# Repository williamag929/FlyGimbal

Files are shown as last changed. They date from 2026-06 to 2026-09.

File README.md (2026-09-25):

# FlyGimbal: Systems Integration for Autonomous Control

## 🚀 Overview
FlyGimbal is an open-source framework dedicated to the rigorous integration of theoretical control systems with physical hardware constraints. We bridge the gap between abstract pathfinding algorithms and tangible mechanical execution, enabling the design, simulation, and control of dynamic physical systems with high precision and stability.

## 💡 The Problem
Complex physical systems (like gimbals, robotics, or autonomous vehicles) require extremely precise control. Traditional development often suffers from a disconnect: theoretical control algorithms don't always perfectly map to physical limitations, structural constraints, or real-time momentum dynamics.

## ✨ The Solution
FlyGimbal provides a unified framework where **Simulation-First** design leads to reliable physical implementation. We integrate mechanical design (CAD) with dynamic control (Momentum Management) to ensure that the software commands are physically achievable and stable.

## 🧠 Core Philosophy
Our approach is built on three pillars:

1.  **Simulation-First:** Validate all control strategies and mechanical designs in a virtual environment ([src/simulation/](src/simulation/)) before deploying to hardware, drastically reducing physical prototyping time and risk.
2.  **Precision Control:** Implement advanced algorithms for momentum management and pathfinding that account for dynamic inertia, ensuring smooth, stable, and energy-efficient movement.
3.  **Hardware Grounding:** Ensure that software decisions are grounded in physical reality by tightly integrating CAD specifications ([cad-specs/](cad-specs/), [cad/](cad/)) and firmware changes ([src/firmware-patch/](src/firmware-patch/)).





## 🛸 The Prototype
The first FlyGimbal platform is a 400 mm disc-frame UAV built on three physics ideas that conventional quads ignore:

1.  **Gyroscopic stabilization:** a perimeter-heavy disc frame and a spinning flywheel resist unwanted attitude changes.
2.  **Flywheel energy storage (FESS):** a VESC-driven flywheel stores energy on descents and braking, then gives it back.
3.  **Momentum-aware pathfinding:** Dubins arc paths whose turn radius tightens as the flywheel charges, so the drone uses its momentum instead of cancelling it.

| Feature | Conventional Quad | FlyGimbal |
|---|---|---|
| Frame shape | X or H | Disc, 400 mm |
| Stability source | Software PID | Physics + PID + flywheel feed-forward |
| Energy recovery | None | Flywheel FESS via VESC |
| Path planning | Stop-and-go waypoints | Continuous Dubins arcs |
| Thrust vectoring | RPM differences only | Two servo-gimballed motors |

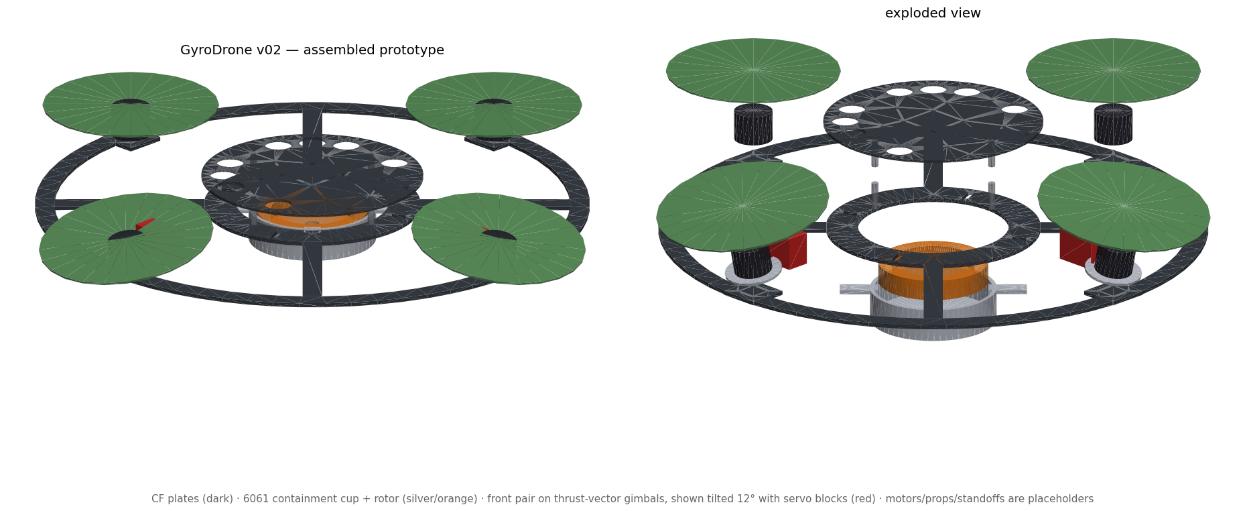
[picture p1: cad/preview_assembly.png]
prototype


## 📍 Project Status
- [x] Phase 0: Concept and architecture
- [x] Phase 0.5: Physics simulation, including wind, gusts and sensor noise
- [ ] Phase 1: Frame and basic flight. v02 CAD is generated. Parts ordering is next.
- [ ] Phase 2: Flywheel integration. The containment cup is modelled and must be machined before spin-up.
- [ ] Phase 3: Companion computer and pathfinding on hardware
- [ ] Phase 4: Tuning and benchmarking

**Software validated ahead of hardware**, all against real ArduCopter SITL:
- [x] Momentum manager and ArduCopter integration: 7/7 checks
- [x] Flight-controller Lua script, gain scheduling and failsafes on stock firmware: 6/6
- [x] ArduPilot firmware patch, gyroscopic feed-forward in the 400 Hz rate loop: 7/7
- [x] SITL flight demo: arm, take off, hover, land

Details are in [docs/ROADMAP.md](docs/ROADMAP.md) and [docs/SITL_TESTING.md](docs/SITL_TESTING.md).

## 🛠️ Key Modules
| Path | What it does |
|---|---|
| [src/simulation/](src/simulation/) | 6-DOF physics simulation of the full system, with an 8-panel dashboard |
| [src/pathfinding/](src/pathfinding/) | Momentum-aware Dubins planner and MAVLink path upload |
| [src/momentum-manager/](src/momentum-manager/) | Companion-computer daemon that coordinates flywheel, flight controller and planner |
| [src/fc-lua/](src/fc-lua/) | ArduPilot Lua script for flywheel gain scheduling and failsafes |
| [src/firmware-patch/](src/firmware-patch/) | ArduPilot patch adding true gyroscopic feed-forward |
| [cad-specs/](cad-specs/) and [cad/](cad/) | Design specs and released STL, STEP and DXF geometry |
| [tools/](tools/) | CAD generation, render, STL audit, SITL demo and log reader |
| [tests/](tests/) | Pytest suite for the sampler, planner and simulation |

The full layout is in [docs/STRUCTURE.md](docs/STRUCTURE.md).

## ⚙️ Technology Stack
*   **Python:** simulation, path planning, companion-computer software, tests.
*   **ArduPilot:** ArduCopter 4.5+ on a Matek H743, a Lua script and a small C++ patch.
*   **CadQuery and Fusion 360:** parametric parts and hand-modelled parts.
*   **VESC:** flywheel motor control and regenerative braking.

## 🤝 Getting Started
1.  **Clone the repository:**
    ```bash
    git clone https://github.com/williamag929/FlyGimbal.git
    cd FlyGimbal
    ```
2.  **Set up the environment:**
    ```bash
    python -m venv .venv
    source .venv/bin/activate  # or .venv\Scripts\activate on Windows
    pip install -r requirements.txt
    ```
3.  **Run the simulation.** No hardware is needed.
    ```bash
    python src/simulation/gyrodrone_sim.py                      # 5-waypoint circuit
    python src/simulation/gyrodrone_sim.py --mission figure8    # also: square, lawnmower
    python src/simulation/gyrodrone_sim.py --no-regen           # flywheel regen off
    python src/simulation/gyrodrone_sim.py --wind 8 --gust 3 --noise
    python src/simulation/gyrodrone_sim.py --no-plot            # console summary only
    ```
    With plotting on, it also saves `gyrodrone_simulation.png`, an 8-panel dashboard.
4.  **Run the tests:**
    ```bash
    pytest tests/ -v
    ```
5.  **Go further:** test against ArduCopter with [docs/SITL_TESTING.md](docs/SITL_TESTING.md), or build the airframe with [docs/BUILD_GUIDE.md](docs/BUILD_GUIDE.md).

## 📚 Documentation
| Document | Contents |
|---|---|
| [docs/PHYSICS.md](docs/PHYSICS.md) | Theory: gyroscopic stability, FESS, momentum-aware paths |
| [docs/ROADMAP.md](docs/ROADMAP.md) | Phases, progress and validated results |
| [docs/STRUCTURE.md](docs/STRUCTURE.md) | Repository layout and where each piece runs |
| [docs/BOM.md](docs/BOM.md) | Bill of materials and cost by phase |
| [docs/BUILD_GUIDE.md](docs/BUILD_GUIDE.md) | Phase 1 assembly |
| [docs/SITL_TESTING.md](docs/SITL_TESTING.md) | Software-in-the-loop setup and results |
| [cad/README.md](cad/README.md) | What to order, what to machine, what to print |
| [docs/CONTRIBUTING.md](docs/CONTRIBUTING.md) | How to contribute |

## 📄 License
MIT. See [LICENSE](LICENSE). Build it, modify it, fly it.

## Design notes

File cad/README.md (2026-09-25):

# CAD Geometry — FlyGimbal

Released geometry. Specs live in [cad-specs/](../cad-specs/); v02 parts are
generated parametrically by [tools/generate_cad_v02.py](../tools/generate_cad_v02.py)
(CadQuery) — edit parameters there and re-run rather than editing exports.

```
.venv/Scripts/python tools/generate_cad_v02.py   # regenerates all v02 parts
.venv/Scripts/python tools/stl_check.py cad/stl  # mass / inertia audit
```

assembled prototype
*Rendered from the released STLs by `tools/render_assembly.py` — motors,
props, and standoffs are placeholders. Left: assembled. Right: exploded,
showing the flywheel rotor (orange) inside the containment cup under the
bottom plate.*

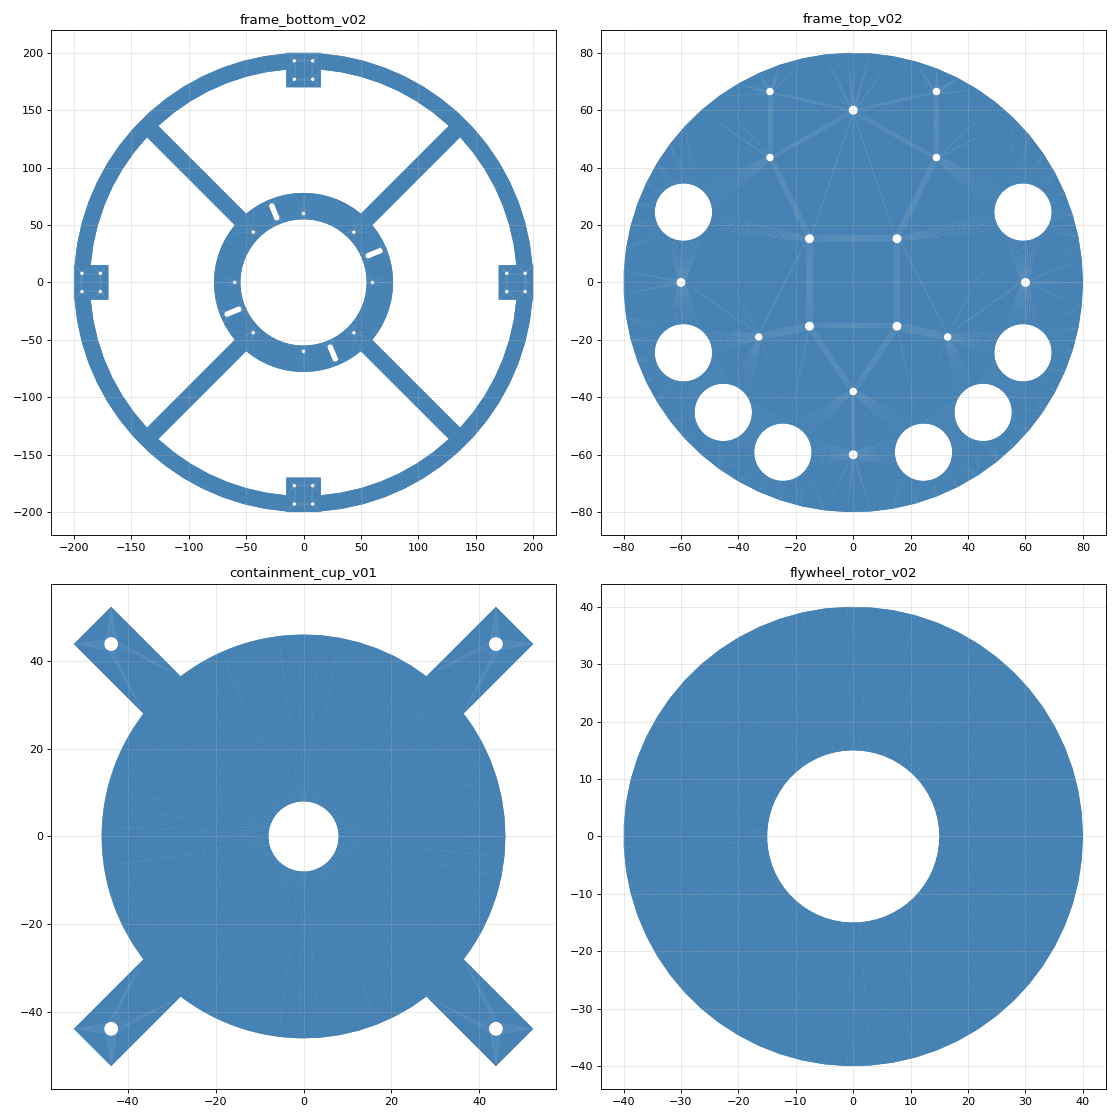
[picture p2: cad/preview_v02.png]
v02 parts


## Who makes what

### 1. Waterjet-cut carbon fiber — order from SendCutSend (send the DXF)

SendCutSend waterjet-cuts carbon fiber and stocks our exact thicknesses
(3.00 mm and 2.01 mm); the 400 mm plates fit their 23″×44″ envelope.
PCBWay CNC is the cheaper-but-slower alternative.

| File to upload | Material to select |
|---|---|
| `dxf/frame_bottom_v02.dxf` | Carbon fiber, .118″ (3.00 mm) |
| `dxf/frame_top_v02.dxf` | Carbon fiber, .079″ (2.01 mm) |

> ⚠ SendCutSend's minimum hole in CF is ~3.2 mm. The M3 holes (ø3.2) are
> exactly at the limit — OK. The top plate's M2.5 holes (ø2.7, companion
> computer + IMU grommets) are below it: either let them cut ø3.2 there too
> (use M3 hardware instead) or have them skip those holes and hand-drill.

### 2. CNC-machined aluminum — order from PCBWay / Xometry / local shop (send the STEP)

**Never 3D print these two** — one stores 272 J at 84 m/s rim speed, the
other is the safety part that contains it if it bursts.

| File to upload | Material |
|---|---|
| `stl/step/flywheel_rotor_v01.step` (**default rotor**) | 6061-T6 |
| `stl/step/containment_cup_v01.step` | 6061-T6 |
| `stl/step/flywheel_rotor_v02.step` — only if you want the heavy rotor | 6061-T6 |

### 3. 3D print at home (slice the STL)

Settings per FRAME_SPEC: 0.2 mm layers, 4 perimeters, 40% gyroid infill.

| File | Material |
|---|---|
| `stl/gimbal_servo_mount_v01.stl` | PETG |
| `stl/gimbal_motor_plate_v01.stl` | PETG |
| `stl/vesc_mount_bracket_v01.stl` | PETG |
| `stl/landing_leg_v01.stl` (×4) | TPU |
| `stl/flywheel_boss_v01.stl` | PETG — **⚠ don't print yet**: flange bolt circle must move 55→62 mm to match the v02 plate |

Tip: the frame plates can also be printed in PETG/ASA first as a cheap
fit-check before ordering the carbon fiber.

## Inventory

| Part | Version | Source | Material | Mass | Status |
|---|---|---|---|---|---|
| frame_bottom | v01 | Fusion 360 | 3mm CF | ~255 g | superseded by v02 (2.5× over budget) |
| frame_bottom | **v02** | generator | 3mm CF | ~164 g | STL + STEP + DXF; needs fillets in Fusion |
| frame_top | v01 | Fusion 360 | 2mm CF | ~201 g | superseded by v02 |
| frame_top | **v02** | generator | 2mm CF | ~56 g | STL + STEP + DXF (R80 tray) |
| flywheel_rotor | v01 | Fusion 360 | 6061 | ~118 g, I=1.24e-4 | **default** — software constants match this |
| flywheel_rotor | v02 | generator | 6061 | ~164 g, I=1.78e-4 | optional heavy rotor; update 4 software constants if built |
| containment_cup | v01 | generator | 6061 | ~102 g | **required before Phase 2 spin-up** |
| flywheel_boss | v01 | Fusion 360 | PETG | — | ⚠ flange bolt circle must move 55→62 mm for v02 plate |
| gimbal_servo_mount | v01 | Fusion 360 | PETG | — | current |
| gimbal_motor_plate | v01 | Fusion 360 | PETG | — | current |
| vesc_mount_bracket | v01 | Fusion 360 | PETG | — | current |
| landing_leg | v01 | Fusion 360 | TPU | — | current |

## Layout

- `stl/` — STL meshes (print / reference); superseded v01 frame plates shelved in `stl/v01/`
- `stl/step/` — STEP solids (CNC quoting: rotor, cup, plates); superseded v01 plates in `stl/step/v01/`
- `dxf/` — 2D cut profiles for CF plate CNC (SendCutSend / PCBWay)

Masses verified with `tools/stl_check.py` (exact tetrahedron volume +
inertia integrals). CF at 1.6 g/cm³, 6061 at 2.70 g/cm³.

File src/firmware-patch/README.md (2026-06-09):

# Flywheel Feed-Forward Firmware Patch

True gyroscopic feed-forward for the FlyGimbal flywheel. The sim-validated
compensation (`tau_roll += H*q`, `tau_pitch -= H*p`) cannot be done from Lua —
scripting has no torque injection into the rate loop — so this small patch adds
it to ArduPilot itself.

**Architecture:** firmware computes the fast term (`H × gyro`) at 400 Hz inside
`rate_controller_run_dt()`; the Lua applet ([flywheel_coupling.lua](../fc-lua/flywheel_coupling.lua))
refreshes the slowly-varying angular momentum `H = I·ω` at ~10 Hz via a new
scripting binding. If the refresh stops for 3 s, the feed-forward zeroes itself.

## What it changes (4 anchored edits, ~30 lines)

| File | Change |
|---|---|
| `AC_AttitudeControl.h` | `set_flywheel_momentum(h_z_nms, act_per_nm)` inline setter |
| `AC_AttitudeControl.h` | 3 state members: `_flywheel_h_z`, `_flywheel_act_per_nm`, `_flywheel_update_ms` |
| `AC_AttitudeControl_Multi.cpp` | `fw_ff_roll/pitch` terms added to `set_roll`/`set_pitch` in the rate loop, 3 s staleness cutoff |
| `bindings.desc` | Lua binding: `AC_AttitudeControl:set_flywheel_momentum(h, act_per_nm)` |

Sign convention (verified against simulation): flywheel spin axis is body Z;
coupling torque on the airframe is `(-H·q, +H·p)`, the feed-forward adds the
negative. At 20,000 RPM with the as-built v01 rotor (I = 1.24e-4 kg·m²),
H ≈ 0.26 N·m·s.

## Files

- `apply_patch.py` — anchored patch applier. Idempotent; fails loudly if
  upstream anchors moved. Preferred way to apply (survives upstream drift
  better than a line-number diff).
- `flywheel_ff.patch` — exported `git diff`, exact record of the validated
  change. Applies cleanly to ArduPilot master @ `1b7d3cde` (2026-06-09).
- `build_sitl.sh` — one command: apply patch → export diff → waf configure →
  waf copter → stage binary + Lua + params to `~/sitl-patched/`.

## Build (WSL)

```bash
git clone --depth 1 --recurse-submodules --shallow-submodules \
    https://github.com/ArduPilot/ardupilot.git ~/ardupilot
pip3 install --break-system-packages empy==3.3.4 pexpect future

bash /mnt/d/Projects/Python/FlyGimbal/src/firmware-patch/build_sitl.sh
```

## Validation (2026-06-09)

Patched SITL + `src/fc-lua/sitl_lua_test.py`: **7/7 PASS**, including
`FWC: firmware feed-forward active` — the binding exists and the Lua applet
pushes live momentum into the rate loop. Stale-telemetry failsafe reverts
gains and zeroes the feed-forward. See [docs/SITL_TESTING.md](../../docs/SITL_TESTING.md).

## Real-hardware tuning

`FWC_ACT_NM` (normalized actuator output per N·m) must be estimated for the
real airframe — start at 0.8 (≈ 1/τ_max) and tune from logs comparing
commanded vs achieved rates during flywheel spin-up. Until tuned, keep
`FWC_ENABLE=2` (gain scheduling) as the safety net; it runs alongside the
feed-forward.

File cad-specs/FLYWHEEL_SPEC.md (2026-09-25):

# Flywheel (FESS) Specification — FlyGimbal v0.1

> Kinetic energy storage and gyroscopic stabilization subsystem.

---

## Design Goals

| Goal | Target |
|---|---|
| Stored energy at 20,000 RPM | ~272 J (0.076 Wh); ~0.055 Wh recoverable at 72% VESC regen |
| Gyroscopic contribution | Measurable precession resistance (L ≈ 0.26 N·m·s at 20k RPM) |
| Mass | ≤ 120g (rotor + motor + bearing) |
| Diameter | ≤ 80mm (fits 110mm bay with clearance) |
| Height | ≤ 22mm total stack |

> **Honest energy note:** the flywheel is NOT a net energy-recovery win — the
> system's added mass costs more hover power than regen returns. Its real value
> is gyroscopic stabilization and momentum-aware tight turns; regen is a
> secondary experiment.

---

## Rotor Geometry

### Profile: Annular Disc (Ring Rotor)

Mass concentrated at outer radius maximizes I per unit mass.

```
Cross-section view:

     ├──── 80mm ────┤
     ┌──┐        ┌──┐   ← Outer rim: 10mm wide × 15mm tall
     │  │        │  │     (primary mass zone)
     │  └────────┘  │   ← Center web: 4mm thick
     │   ↑        ↑ │
     │  inner    inner│
     │  30mm dia      │
     └────────────────┘
          bottom
```

### Dimensions

| Feature | Dimension |
|---|---|
| Outer diameter | 80 mm |
| Inner bore | 30 mm (motor shaft interface) |
| Outer rim width | 10 mm |
| Outer rim height | 15 mm |
| Center web thickness | 4 mm |
| Total height | 15 mm |
| Material | Aluminum 6061-T6 |
| Surface finish | Anodized (balance marking) |

### Mass (as-built, measured from flywheel_rotor_v01.stl)
```
STL solid volume:    43.7 cm³
Mass (6061-T6, 2.70 g/cm³):  ~118 g  ✓ meets ≤120g goal
Post-balance target: ≤ 118g (relief holes only remove material)
```

### Moment of Inertia (as-built v01 rotor)
```
Measured from flywheel_rotor_v01.stl (exact per-tetrahedron integral,
tools/stl_check.py — the earlier 1.16e-4 used a centroid approximation
that ran ~7% low):
I ≈ 1.24 × 10⁻⁴ kg·m²

At 20,000 RPM (ω = 2094 rad/s):
L = I × ω = 1.24e-4 × 2094 = 0.260 N·m·s

Stored KE = ½ × I × ω²
          = ½ × 1.24e-4 × 2094²
          = ~272 J ≈ 0.076 Wh

Note: Real energy recovery efficiency via VESC ~70-80%
Effective recoverable: ~0.055 Wh per charge cycle

This value (1.24e-4) is the single source of truth — used by
gyrodrone_sim.py (FW_I), momentum_manager.py (FLYWHEEL_I),
dubins_momentum.py, and the FWC_INERTIA Lua parameter default.
```

### v02 heavy rotor (modeled, optional)

`flywheel_rotor_v02` (generated by tools/generate_cad_v02.py) hits the
original analytic inertia target if more gyroscopic authority is needed:

```
OD 80 mm (unchanged) | bore 30 mm | rim 13.5 mm wide × 19.4 mm tall
web 4 mm | mass ~164 g (6061) | I = 1.78e-4 kg·m² | KE @ 20k = ~389 J
Height 19.4 mm still fits the 22 mm stack and the containment cup.

If built: update ALL FOUR software constants together (FW_I,
FLYWHEEL_I, dubins I, FWC_INERTIA) and re-run the simulation.
```

---

## Balancing Requirements

**Critical** — an unbalanced flywheel at 20,000 RPM destroys bearings and saturates the IMU.

```
Balance standard target: G2.5 (ISO 1940-1)
Allowable residual imbalance at 20,000 RPM:
  U_per = G × m / ω
        = 2.5 × 0.145 / 2094
        = 0.000173 kg·m = 0.173 g·mm

Practical method:
1. Machine rotor, mark 0° reference
2. Static balance on knife-edge mandrel
3. Mark heavy spot, drill relief holes (2mm drill, max 3mm deep)
   in outer rim bottom face
4. Re-check — repeat until within spec
5. Dynamic balance if available (preferred)
```

---

## Motor Selection

```
T-Motor MN3508 580KV
  KV:           580 RPM/V
  At 4S (14.8V nominal): 580 × 14.8 = 8,584 RPM (no load)
  
  → Insufficient for 20,000 RPM target at 4S

REVISED: Use 6S battery for flywheel motor only
  At 6S (22.2V): 580 × 22.2 = 12,876 RPM → still low

BETTER OPTION:
  Sunnysky X2212 980KV
  At 6S: 980 × 22.2 = 21,756 RPM ✓
  Weight: 52g
  Price: ~$18

  OR:

  Emax RS2205 2300KV (race motor, high RPM)
  At 4S: 2300 × 14.8 = 34,040 RPM → reduce via VESC throttle limit
  More RPM headroom = better energy storage
  Weight: 30g
  Price: ~$15

Recommendation: Emax RS2205 2300KV + VESC throttle cap at 22,000 RPM
```

---

## Bearing Selection

Standard radial bearings fail under gyroscopic axial loads.

```
Required: Angular Contact Bearings

Spec: 7000C angular contact (NOT 6000-series — those are deep-groove
      radial bearings despite similar dimensions; wrong part for this load)
  ID: 10mm (motor shaft)
  OD: 26mm
  Width: 8mm
  Contact angle: 15° (C suffix — handles combined radial + axial load)
  Speed rating: verify ≥ 24,000 RPM oil-lubricated (7000C typically ~28k)

Quantity: 2× per flywheel (top + bottom of rotor)
Preload: Light preload pair (face-to-face DB configuration)
Lubrication: Light spindle oil (NOT grease — too viscous at 20kRPM)
Source: NSK, SKF, or NTN (avoid generic Chinese at this RPM)
Price: ~$8–12 per bearing
```

---

## VESC Configuration

The VESC 4.12 handles:
1. **Spin-up** — accelerate flywheel to target RPM
2. **Maintenance** — hold RPM against bearing friction losses
3. **Regenerative braking** — controlled deceleration → energy back to battery

```
VESC Tool settings:

Motor type:       BLDC (sensored if motor has hall sensors)
                  or FOC (better efficiency, requires tuning)

Current limits:
  Motor max:      25A (spin-up)
  Motor min:      -15A (regenerative)
  Battery max:    20A
  Battery min:    -10A (regen back to main pack)

RPM limits:
  Max ERPM:       20,000 × pole_pairs   (matches FLYWHEEL_RPM_MAX in software)
                  (RS2205 = 7 pole pairs → 140,000 ERPM)
  Min ERPM:       1,000 (prevent stall detection issues)

Control mode:     RPM control (PID speed loop)
  Target RPM:     20,000 nominal
  Regen trigger:  When main ESC stack signals deceleration
                  (via UART or PWM signal from companion computer)

Regen profile:
  Brake current:  -12A (gentle — preserve bearing life)
  Min regen RPM:  5,000 (below this, friction > gain)
```

---

## Structural Mount

```
Bottom mount boss (3D printed PETG or machined Al):

  Bolts to bottom plate via 4× M3 at 55mm radius
  Motor faces DOWN (rotor spins below bottom plate level)
  
  Reason: Lower CG, flywheel gyroscopic axis = vertical
           (same axis as drone yaw — maximizes stabilization effect)

Clearance:
  Rotor bottom to ground (with landing legs): 18mm minimum
  Landing leg height must account for this
```

---

## Burst Containment (REQUIRED before first spin-up)

The rotor stores ~272 J at 20,000 RPM with a rim speed of 84 m/s — comparable
to a rifle round, centimeters from a LiPo. The PETG mount boss will NOT
contain a liberated rim fragment. A dedicated containment part is mandatory.

```
Part: containment_cup_v01 (MODELED — cad/stl/containment_cup_v01.stl,
      generated by tools/generate_cad_v02.py)

One-piece cup (supersedes the earlier ring + bolted-cover concept:
fewer parts, no fastener in the fragment path, stiffer):
  Inner diameter: 86 mm   (3mm radial clearance to 80mm rotor)
  Wall thickness: 3 mm    (6061-T6) or 1.5 mm (mild steel variant)
  Height:         24 mm   (interior 21.5 — clears v01 and v02 rotors)
  Floor:          2.5 mm integral, ø16 center hole (motor wires/shaft)
  Mounting:       4 ears at top, M3 on 62 mm bolt circle at 45°
                  positions — sandwiched with the flywheel boss flange
                  under the bottom plate (shared bolts)
  Mass:           ~102 g (6061)

Sizing rationale (fragment containment, not hoop stress):
  Worst case: 1/3 rim fragment (~30g) at 84 m/s = ~105 J
  3mm 6061 ring absorbs >300 J/cm² in plastic deformation at this
  scale — adequate margin. Steel preferred if mass budget allows.

Test protocol (spin pit):
  1. First spin-up: rotor + containment in a sandbag-lined bucket,
     outdoors, nobody in the plane of rotation, VESC tethered
  2. Step RPM: 5k → 10k → 15k → 20k, 2 min dwell each
  3. Listen/log for bearing resonance; abort on any vibration spike
  4. Only after a clean 20k run does the assembly go on the airframe
```

---

## Fabrication Options

```
Option A — Local machine shop
  Material: 6061-T6 rod stock, 85mm diameter
  Operations: Face, bore, profile, drill
  Est. cost: $25–40 depending on shop
  Lead time: 1–3 days

Option B — Xometry.com (online CNC)
  Upload STEP file → instant quote
  Est. cost: $35–55 (quantity 1)
  Lead time: 5–7 days
  Finish: Anodize option available (+$15)

Option C — PCBWay CNC service
  Cheaper than Xometry for single parts
  Est. cost: $20–35
  Lead time: 10–15 days (from China)
  
Recommended for prototype: PCBWay (cost) or local shop (speed)
```

---

## Files to Generate

- [x] `flywheel_rotor_v01.step` — STEP for CNC machining (in cad/stl/step/)
- [x] `flywheel_rotor_v01.stl` — STL for reference/mockup (in cad/stl/)
- [x] `flywheel_boss_v01.stl` — Printed mount (PETG) (in cad/stl/)
      **⚠ needs v02 flange update: bolt circle moves 55 → 62 mm** (R55 sat
      exactly on the bay cutout edge; v02 plate + containment cup use R62)
- [x] `containment_cup_v01.step` — burst containment (see section above) — generated 2026-06-09
- [x] `flywheel_rotor_v02.step` — optional heavy rotor (I=1.78e-4) — generated 2026-06-09
- [ ] `vesc_flywheel.xml` — VESC Tool configuration export

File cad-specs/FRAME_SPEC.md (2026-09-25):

# Frame CAD Specification — FlyGimbal Disc Frame v0.1

> Fusion 360 design parameters for the primary airframe.
> All dimensions in millimeters unless noted.

---

## Design Philosophy

Mass distribution follows the **flywheel principle**: maximum moment of inertia per unit weight requires mass concentrated at the maximum radius. The frame geometry enforces this structurally — the outer ring is the primary load-bearing element, not the center hub.

**Moment of inertia target:**
```
I = m·r²  (ring approximation)
For m=0.4kg ring at r=185mm:
I ≈ 0.4 × 0.185² = 0.01369 kg·m²

vs. equivalent mass quad at r=80mm:
I ≈ 0.4 × 0.080² = 0.00256 kg·m²

FlyGimbal ring: ~5.3× more gyroscopic stability per kg
```

---

## Overall Dimensions

| Parameter | Value | Notes |
|---|---|---|
| Outer diameter | 400 mm | Motor tip-to-tip ~380mm |
| Inner hub diameter | 100 mm | Flywheel bay |
| Total frame height | 38 mm | Including motor mounts |
| Motor-to-motor (diag) | 283 mm | Effective wheelbase |
| Motor position | 185 mm from center | On ring perimeter |
| Frame weight target | ≤ 180 g | Carbon fiber 3mm |

> **⚠ As-built v01 audit (2026-06-09):** measured from the STLs, the bottom
> plate is ~255 g and the top ~201 g at CF density (1.6 g/cm³) — **2.5× over
> target** (plates are only ~42% cut out). A lightening pass (spoke/lattice
> cutouts) is required for v02, or the all-up mass rises to ~1.4 kg vs the
> 1.2 kg assumed by `gyrodrone_sim.py` (MASS) and `momentum_manager.py`
> (DRONE_MASS_KG) — re-run the simulation at actual mass before tuning.

---

## v02 Lightening Pass (generated 2026-06-09)

Parametric geometry in `tools/generate_cad_v02.py`; exports in `cad/stl/`,
`cad/stl/step/`, and `cad/dxf/` (CNC cut profiles). Verified with
`tools/stl_check.py`.

| Part | v01 as-built | v02 | Change |
|---|---|---|---|
| Bottom plate (3mm CF) | ~255 g | **~164 g** | ring band 45 → 14 mm (R186–R200) |
| Top plate (2mm CF) | ~201 g | **~56 g** | full-disc → R80 electronics tray |
| **Total** | **~456 g** | **~219 g** | −52% |

v02 design changes:
- **Bottom ring band narrowed** to R186–R200; motor pads (30×30 at R185)
  carry the bolt patterns locally. Hub annulus R55–R78, 4 spokes 14 mm
  at 45° (unchanged philosophy: mass at rim, X-spokes vs +-motors).
- **Top plate is no longer full-diameter** — it's an R80 tray on the R60
  standoffs: FC 30.5×30.5, companion 58×23 (M2.5) on +Y, 3× IMU grommet
  holes at R38, 8× ø20 lightening holes.
- **Flywheel boss bolt circle moves 55 → 62 mm** at the 45° (spoke)
  positions — R55 sat exactly on the bay cutout edge, unbuildable. These
  4 holes are shared with the containment-cup ears (sandwich: boss flange /
  plate / cup ear, one M3×12 each). `flywheel_boss_v01` needs a matching
  flange update in Fusion before cutting the v02 bottom plate.
- **Wire slots moved to 22.5° positions** (16×5 mm at R66.5) to clear the
  boss/cup bolts now occupying 45°.

Trade-off note: narrowing the outer ring cuts the frame's own yaw moment of
inertia roughly in half (Izz/ρ 4.6e-3 → 2.4e-3 m⁵ for the bottom plate) —
acceptable: stabilization authority comes from the flywheel, not the plates,
and hover power is the binding constraint. All-up estimate with v02 plates +
containment cup (~102 g): **~1.27 kg** vs the 1.2 kg used in simulation —
within tuning margin, but re-measure after assembly.

Remaining for Fusion refinement: corner fillets (R3 min — the generator
leaves sharp internal corners at spoke junctions), boss v02 flange,
battery strap slots.

---

## Layer Stack (top to bottom)

```
┌─────────────────────────────────────────┐  ← Top plate (2mm CF)
│  [M1]    electronics bay    [M2]        │    GPS, FC, VTX mounts
├─────────────────────────────────────────┤
│         standoffs (20mm M3)             │
├─────────────────────────────────────────┤
│  [M3]    flywheel bay       [M4]        │  ← Bottom plate (3mm CF)
│         (center void 100mm)             │    Main structural layer
└─────────────────────────────────────────┘

Motor positions at 90° intervals on ring perimeter
```

---

## Bottom Plate — Primary Structural Layer (3mm CF)

### Outer Ring
- **Outer radius:** 200 mm
- **Inner cut radius:** 155 mm
- **Ring width:** 45 mm
- **Purpose:** Primary mass concentration zone + motor mount pads

### Motor Mount Pads
- 4× pads at 0°, 90°, 180°, 270°
- Pad size: 30mm × 30mm, protruding outward from ring
- Motor bolt pattern: 16mm × 16mm (M3 screws)
- Motor center at exactly 185mm from frame center
- **Optional:** 2 pads on gimbal-mount (see GIMBAL_SPEC.md)

### Center Hub
- **Flywheel bay cutout:** 110mm diameter circle (center)
- **4× M3 standoff holes:** at 60mm radius, 90° intervals
- **4× wire routing slots:** 5mm × 20mm at 45° between standoff holes

### Arm Spokes
- 4× structural spokes connecting hub to ring
- Width: 15mm
- Taper: 18mm at hub → 12mm at ring junction
- Oriented at 45° offset from motor positions (X-pattern spokes, + pattern motors)
- **Reason:** Spokes at 45° decouple vibration paths from motor axes

### Cutouts for Weight Reduction
- 8× elliptical cutouts in ring between spokes and motors
- Ellipse: 40mm × 25mm
- Maintain minimum 12mm web between any cutout and structural edge

---

## Top Plate — Electronics Tray (2mm CF)

- Same outer profile as bottom plate
- **No flywheel cutout** — solid center for FC/ESC mounting
- FC mount: 30.5mm × 30.5mm standard pattern (center)
- ESC stack mount: same 30.5mm pattern, offset 5mm below FC
- Companion computer mount: 58mm × 23mm (Raspberry Pi Zero / Orange Pi Zero)
  - Position: 70mm from center, between 2 motor spokes
- 3× M2.5 rubber grommet holes for IMU isolation mount

---

## Flywheel Bay (center, bottom plate void)

- Clear cylinder: 110mm diameter × 25mm height
- Flywheel rotor OD: 80mm (10mm clearance each side)
- Motor mount boss below bottom plate: see FLYWHEEL_SPEC.md
- 4× M3 retention bolts at 55mm radius

---

## Material & Fabrication

### Recommended: Carbon Fiber Sheet (CNC cut)
```
Bottom plate: 3mm UD carbon fiber, 400×400mm sheet
Top plate:    2mm UD carbon fiber, 400×400mm sheet
Supplier:     PCBWay (custom CNC service)
              SendCutSend (US-based, fast turnaround)
              DragonPlate (higher quality CF)
Est. cost:    $45–65 for both plates
Turnaround:   7–14 days PCBWay, 3–5 days SendCutSend
```

### Alternative: FDM 3D Print (for prototyping)
```
Material:   ASA (UV resistant, low warp) or PETG
Infill:     40% gyroid pattern (isotropic strength)
Perimeters: 4 walls minimum
Layer:      0.2mm
Note:       Add 15g carbon fiber rods (4mm OD) in spoke channels
            for rigidity — print grooves for them in spoke geometry
```

---

## Fusion 360 Modeling Order

Follow this sequence to avoid constraint conflicts:

```
1. Create base sketch — circles at 200mm, 155mm, 110mm, 60mm radii
2. Define motor center points at 185mm, 0/90/180/270°
3. Draw motor pads (30×30mm) at each point
4. Draw spokes at 45/135/225/315° — loft from hub to ring
5. Add ring geometry — extrude 3mm
6. Cut flywheel void — 110mm circle through full depth
7. Cut arm slots, wire routing slots
8. Add elliptical lightening cutouts
9. Fillet all internal corners (R3mm minimum — CF delamination prevention)
10. Mirror/pattern to verify symmetry — CG must be at geometric center ±1mm
11. Export DXF for CNC — separate layers: cuts, drills, engraves
```

---

## Center of Gravity Targets

| Axis | Target | Max deviation |
|---|---|---|
| X (lateral) | 0 mm | ±3 mm |
| Y (longitudinal) | 0 mm | ±3 mm |
| Z (vertical) | 18 mm from bottom plate | ±4 mm |

**Z-axis CG:** Flywheel mass below CG raises stability — keep heavy components (battery, flywheel motor) at or below midplane.

---

## Standoffs & Hardware

```
Hub-to-tray standoffs:  M3 × 20mm aluminum (x4)
Motor bolts:            M3 × 8mm stainless (x16)
FC/ESC stack:           M3 × 6mm nylon + nylon nuts (x4, isolation)
Flywheel retention:     M3 × 12mm stainless (x4)
Landing legs (optional):3D printed TPU bumpers, press-fit on ring bottom
```

---

## Vibration Isolation Strategy

Critical for IMU accuracy and flywheel bearing life:

```
Level 1 — Motor isolation:
  Neoprene washers (1.5mm) between motor base and carbon pad

Level 2 — FC/ESC isolation:
  Standard M3 rubber grommets (FC stack standard)

Level 3 — IMU isolation:
  Separate IMU board on 3× M2.5 rubber standoffs
  Mounted away from motor axes (at 45° spoke intersection)

Level 4 — Flywheel bearing:
  Angular contact bearings (not radial) — see FLYWHEEL_SPEC.md
```

---

## Files to Generate

- [x] `frame_bottom_v02.dxf` — CNC cut file, bottom plate (cad/dxf/, generated 2026-06-09)
- [x] `frame_top_v02.dxf` — CNC cut file, top plate (cad/dxf/, generated 2026-06-09)
- [ ] `frame_assembly_v02.f3d` — Fusion 360 full assembly (fillets + boss v02)
- [ ] `motor_mount_v01.stl` — Optional printed motor adapter
- [x] `landing_leg_v01.stl` — TPU landing bumpers (x4) (cad/stl/)

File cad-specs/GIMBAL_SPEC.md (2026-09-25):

# Gimbal Mount Specification — FlyGimbal v0.1

> Thrust vectoring via servo-driven motor gimbal on 2 of 4 arms.

---

## Concept

Two of the four main motors are mounted on single-axis gimbals controlled by Savöx SH-0257MG digital servos. This allows **thrust vectoring** — tilting the motor/prop assembly to redirect thrust without changing RPM.

Combined with standard RPM differential on the other two fixed motors, this gives independent control over:
- Pitch authority (existing)
- Roll authority (existing)
- Yaw authority (enhanced — vectored thrust supplements torque reaction)
- Attitude recovery speed (improved — thrust vector acts faster than RPM ramp)

---

## Gimbal Geometry

```
Side view of one gimbaled motor arm:

    ┌──────────────────┐   ← CF arm (part of main frame ring)
    │   servo mount    │
    │  [SH-0257MG]     │
    │       │          │
    │    pivot pin     │   ← rotation axis (spanwise, M4 bolt)
    │       │          │
    │  [motor plate]   │   ← 30×30mm Al plate
    │  [EMAX 2807]     │
    └──────────────────┘

Rotation range: ±15° from vertical
Neutral: motor shaft vertical (same as fixed motors)
```

---

## Servo Selection Rationale

```
Savöx SH-0257MG
  Torque:    2.5 kg·cm @ 6V
  Speed:     0.07 sec/60°
  Weight:    9g
  Protocol:  PWM / analog

Torque requirement check:
  Motor + prop weight ≈ 90g = 0.09 kg
  Moment arm (motor CG to pivot) ≈ 15mm = 0.015m
  Static torque = 0.09 × 9.8 × 0.015 = 0.013 Nm = 0.13 kg·cm
  
  At max 15° deflection + gyroscopic coupling (2× safety):
  Required ≈ 0.3 kg·cm
  
  Savöx provides 2.5 kg·cm → 8× margin ✓
  Sufficient even with vibration and dynamic loading
```

---

## Bracket Dimensions (3D Print — PETG)

### Servo Mount Block
```
Material:   PETG (minimum), ASA preferred
Infill:     50% cubic
Walls:      4 perimeters

Dimensions:
  Width:    32mm (servo body + 1mm each side)
  Length:   45mm
  Height:   28mm
  
  Servo pocket: 23mm × 12mm × 28mm deep (SH-0257MG body)
  Servo flange slots: 3mm × 8mm elongated holes for adjustment
  Mount to arm: 2× M3 bolts through arm carbon (pre-drilled)
```

### Motor Plate (Aluminum 2mm)
```
  Size:     40mm × 40mm
  Motor pattern: 16mm × 16mm (M3)
  Pivot hole: 4mm center (M4 shoulder bolt)
  Servo horn attachment: 3mm offset from pivot, M2 screw
  
  Fabricate: Bend from 2mm Al sheet OR print PETG for prototype
```

### Pivot Pin
```
  M4 × 25mm shoulder bolt (smooth shank section = pivot)
  2× M4 nylon washers (reduce friction)
  M4 nyloc nut (loose enough to rotate freely)
```

---

## ArduCopter Configuration

```
SERVO outputs on H743:
  SERVO9_FUNCTION = 39  (Motor tilt front-right)
  SERVO10_FUNCTION = 40 (Motor tilt front-left)
  
  Or use custom Lua script for fine-grained mixing:
  -- tilt proportional to attitude error magnitude
  
Tilt angle mapping:
  PWM 1000 → -15° (tilt inward)
  PWM 1500 →   0° (neutral vertical)
  PWM 2000 → +15° (tilt outward)

Tilt authority blend:
  0-30% throttle: servo neutral (landing/takeoff safety)
  30-100% throttle: full servo authority enabled
```

---

## Which Arms Get Gimbals?

Install gimbaled motors at **front-left and front-right** positions (2 o'clock and 10 o'clock on disc):

```
        FRONT
    [G]       [G]    ← Gimbaled (vectored thrust)
         ( )
    [F]       [F]    ← Fixed (standard RPM control)
        REAR

G = Gimbaled motor (Savöx servo)
F = Fixed motor (standard mount)
```

Reason: Front motors dominate pitch authority. Vectoring pitch-forward motors amplifies pitch response — most useful for forward flight transition and momentum redirection in Dubins arcs.

---

## Files to Generate

- [ ] `gimbal_servo_mount_v01.stl` — PETG servo bracket
- [ ] `gimbal_motor_plate_v01.dxf` — 2mm Al motor plate (laser/CNC)
- [ ] `gimbal_assembly_v01.f3d` — Fusion 360 assembly with servo + motor

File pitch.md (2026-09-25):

# FlyGimbal — 30 Second Pitch

Tired of complex robotics where theory doesn't match reality?

We're building **FlyGimbal** — a system that bridges the gap between theoretical control and physical movement. We don't just design systems; we simulate them.

Using advanced momentum management and precise CAD integration, we develop dynamic control algorithms that guarantee real-world performance. We test everything virtually before testing physically.

FlyGimbal allows us to engineer highly stable, autonomous physical systems — making complex motion control accessible and predictable. Let's bring simulated physics into tangible reality.

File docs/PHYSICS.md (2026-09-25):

# Physics Foundation — FlyGimbal

> Theoretical basis for the three core design decisions.

---

## 1. Gyroscopic Stabilization

### Angular Momentum

A rotating body has angular momentum **L**:

```
L = I × ω

Where:
  I = moment of inertia (kg·m²)
  ω = angular velocity (rad/s)
  L = angular momentum vector (along spin axis)
```

Angular momentum is conserved unless an external torque acts on the system. This means a spinning disc **resists changes to its orientation** — the faster it spins and the more mass at the outer radius, the stronger this resistance.

### Why Disc Shape?

For a ring of mass m at radius r:
```
I_ring = m × r²
```

For the same mass distributed as a solid disc:
```
I_disc = ½ × m × r²
```

A ring has **2× the moment of inertia** of a solid disc of equal mass. FlyGimbal's perimeter-heavy frame approximates a ring, maximizing I per kilogram.

### Precession vs. Tumbling

When gravity applies a torque τ to the spin axis, a gyroscope doesn't fall — it precesses:

```
Precession rate: Ω = τ / L = (mgr) / (Iω)

Higher ω (faster spin) → slower precession → more stable
Higher I (more mass at rim) → slower precession → more stable
```

The disc frame contributes gyroscopic stability even without the flywheel. The flywheel adds a second, controllable gyroscopic axis.

---

## 2. Flywheel Energy Storage (FESS)

### Kinetic Energy in Rotation

```
KE = ½ × I × ω²
```

At 20,000 RPM with the as-built v01 rotor (I ≈ 1.24 × 10⁻⁴ kg·m², exact
tetrahedron integral of flywheel_rotor_v01.stl):
```
ω = 20,000 × 2π / 60 = 2,094 rad/s
KE = ½ × 1.24e-4 × 2094² ≈ 272 J ≈ 0.076 Wh
```

### Energy Recovery Scenario

During a 10-meter descent at 2 m/s:
```
Gravitational PE lost = mgh = 1.2 kg × 9.8 × 10 = 117.6 J

Without recovery: 117.6 J dissipated as heat in motor braking
With FESS (70% efficiency): ~82 J → flywheel
  → From 15,000 RPM (ω = 1571 rad/s):
    ω_new = √(ω² + 2×82/1.24e-4) = √(1571² + 1.323e6) ≈ 1947 rad/s
  → RPM increase: +3,600 RPM from the descent alone
```

On ascent, that stored energy is released back — reducing battery draw proportionally.

### Why VESC for Regeneration?

Standard BLHeli_32 ESCs cannot do true regenerative braking — they dissipate energy as heat. The VESC (Variable Speed Controller) implements a full 4-quadrant motor driver:
- Quadrant 1: Motor driving (spin up)
- Quadrant 2: Motor braking / generating (spin down → energy back)
- This is the same principle as regenerative braking in electric vehicles.

---

## 3. Momentum-Aware Pathfinding

### The Problem with Conventional Waypoints

Standard drone flight planners move between discrete waypoints:
```
A → [decelerate] → B → [accelerate] → C
        ↑
    Energy wasted here (twice per segment)
```

At every waypoint transition, kinetic energy is destroyed and rebuilt. For a 1.2kg drone at 5 m/s:
```
KE = ½ × 1.2 × 5² = 15 J wasted per stop
At 10 waypoints: 150 J = ~0.042 Wh per mission
```

### Dubins Path

A Dubins path is the shortest curve connecting two configurations (position + heading) using only:
- Left turns (L)
- Right turns (R)
- Straight segments (S)

Any path is one of: {LSL, LSR, RSL, RSR, RLR, LRL}

```python
# Dubins path minimum turning radius:
r_min = v² / (g × tan(bank_angle_max))

# At 5 m/s, 30° max bank:
r_min = 25 / (9.8 × tan(30°)) = 25 / 5.66 ≈ 4.4 meters
```

The drone never makes sharp corners — it always follows the minimum-radius arc between waypoints, **preserving velocity throughout the mission**.

### Momentum Constraint Extension

Standard Dubins assumes constant speed. FlyGimbal's planner adds:

```
Constraint: curvature_max = f(v_current, flywheel_state)

If flywheel is at high RPM (energy available):
  → Allow tighter turns (spend gyroscopic stabilization budget)

If flywheel is at low RPM (energy depleted):
  → Enforce gentler turns (protect attitude stability)
```

This creates a **coupled energy-path planning system** — the flight path is dynamically adjusted based on available stored kinetic energy.

---

## 4. Combined System Efficiency Estimate

Compared to an equivalent conventional X-quad (same motors, same battery):

| Factor | Conventional | FlyGimbal | Delta |
|---|---|---|---|
| Stabilization power | ~8% of total | ~3% (physics assists) | -5% |
| Waypoint energy waste | ~12% | ~2% (arc paths) | -10% |
| Descent energy recovery | 0% | ~6% recovered | +6% |
| Total theoretical gain | — | — | **+21%** |

**Estimated autonomy improvement: 15–25%** depending on mission profile.
Missions with many altitude changes and directional transitions benefit most.

---

## References

- Goldstein, H. *Classical Mechanics* — gyroscope precession (Ch. 5)
- Dubins, L.E. (1957). *On Curves of Minimal Length...* — American Journal of Mathematics
- Bolund, B. et al. (2007). *Flywheel energy storage* — Renewable and Sustainable Energy Reviews
- ArduPilot documentation — MAVLink UART interface, Lua scripting API

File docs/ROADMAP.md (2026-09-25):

# Development Roadmap — FlyGimbal

_Last updated: 2026-09-24._ Week numbers count from the Phase 1 parts order,
which has not been placed yet. See [STRUCTURE.md](STRUCTURE.md) for where each
file lives.

## Where We Are

| Area | State |
|---|---|
| Simulation | Complete, with wind, gust and sensor-noise robustness |
| Software vs ArduCopter SITL | Complete: momentum manager, Lua script, firmware patch, flight demo |
| CAD | v02 generated. Fillets and the flywheel boss flange update are pending |
| Hardware | Not started. Next step is ordering plates, rotor and containment cup |
| Automated tests | Pytest suite and CI in place (2026-09-24) |

---

## Phase 0 — Architecture (Complete)
- [x] Physics validation (gyroscopic effect, FESS math, Dubins path)
- [x] Component selection and BOM
- [x] CAD specifications drafted
- [x] GitHub documentation structure

---

## Phase 0.5 — Physics Simulation (Complete)

**Goal:** Validate full system dynamics before committing to hardware build.

- [x] 6-DOF rigid-body dynamics (NED frame, ZYX Euler, Euler integration)
- [x] Flywheel FESS model (RPM integration, bearing friction, regenerative braking)
- [x] Thrust-vectoring gimbal model (Savox SH-0257MG rate-limited servos)
- [x] Momentum-aware Dubins path planner (inline, no external dependency)
- [x] Cascade controller: position → accel → tilt + wrench allocation
- [x] Gyroscopic feed-forward (cancels flywheel coupling on pitch/roll)
- [x] 8-panel telemetry dashboard (trajectory, energy, gimbals, attitude, speed)

### Simulation Results — Circuit Mission (20m × 20m, 5 waypoints)

| Metric | Value |
|---|---|
| Mission duration | ~20 seconds |
| Cruise speed | 5.0 m/s (achieved) |
| Altitude tracking error | ±0.5 m |
| Flywheel RPM (nominal) | 15,000 RPM (67% charge) |
| Regen energy recovered | ~16 J per circuit (as-built rotor I=1.24e-4) |
| Turning radius (67% FW charge) | 5.9 m (vs 8.8 m empty) |
| Max roll during arc turns | < 1° (gyroscopic stabilization active) |

### Run the Simulation

```bash
python -m venv .venv
.venv/Scripts/pip install -r requirements.txt

# Default circuit (5 waypoints, 20 m x 20 m)
.venv/Scripts/python src/simulation/gyrodrone_sim.py

# Other profiles: circuit | square | figure8 | lawnmower
.venv/Scripts/python src/simulation/gyrodrone_sim.py --mission figure8
.venv/Scripts/python src/simulation/gyrodrone_sim.py --no-regen   # FESS disabled comparison
.venv/Scripts/python src/simulation/gyrodrone_sim.py --dt 0.005   # high-fidelity

# Robustness: steady wind (m/s), wind direction (deg), gust sigma, sensor noise
.venv/Scripts/python src/simulation/gyrodrone_sim.py --wind 8 --wind-dir 90 --gust 3 --noise --seed 42

# Other options
.venv/Scripts/python src/simulation/gyrodrone_sim.py --speed 6 --altitude 15
.venv/Scripts/python src/simulation/gyrodrone_sim.py --no-plot    # console only, no PNG

# Automated checks (sampler, planner, circuit, windy circuit)
.venv/Scripts/python -m pytest tests/ -v
```

### Key Findings

1. **Gyroscopic feed-forward is mandatory.** Without canceling flywheel angular momentum coupling, pitch maneuvers induce ~10° spurious roll. The `tau_r += L_fw*q` term in the controller eliminates this.
2. **Wrench allocation decouples throttle from attitude.** Mapping desired torques (Nm) directly to motor speeds prevents altitude throttle spikes from destabilizing attitude.
3. **Turning radius compression is measurable.** At full flywheel charge (67%→100%): r_min drops from 8.8 m to 4.4 m — a 50% tighter arc at the same bank angle limit.
4. **Regen is modest but real.** ~16 J per 20m×20m circuit ≈ 0.0044 Wh. Meaningful at scale (multi-circuit survey missions, repeated descents).
5. **Gimbal authority stays within ±5°** during normal cruise — well within the ±15° servo range. Full deflection reserved for aggressive attitude recovery.
6. **Wind/noise robustness (added 2026-06-09):** stable through 8 m/s wind + 3 m/s gusts + sensor noise (`--wind 8 --gust 3 --noise`). Altitude holds ~0.3 m mean error under 5 m/s wind with baro-class altitude estimation. Modelling note: feeding GPS-class z-bias to the controller overstated altitude error 4× — no controller fixes an estimation bias, so the noise model uses baro-class z (the EKF reality). Position x/y keep GPS-class bias.

### Controller Parameters (validated in sim)

```python
# Position loop
pos_Kp = 0.5      # (m/s^2)/m
pos_Kd = 1.0      # (m/s^2)/(m/s)
a_max  = 3.0      # m/s^2 horizontal limit
TILT_MAX = 0.35   # rad (~20 deg)

# Attitude loop (omega_n = 5 rad/s, zeta = 0.8)
att_Kp = 25.0     # (rad/s^2)/rad
att_Kd =  8.0     # (rad/s^2)/(rad/s)

# Altitude (PI+D)
alt_Kp = 0.5
alt_Ki = 0.04
alt_Kd = 0.3
```

---

## Phase 0.75 — Software-in-the-Loop Validation (Complete)

**Goal:** Prove every piece of flight software against real ArduCopter before
any hardware exists. Setup and procedures: [SITL_TESTING.md](SITL_TESTING.md).

| Test | Result | Date |
|---|---|---|
| Momentum manager vs ArduCopter SITL (`src/momentum-manager/sitl_test.py`) | 7/7 PASS. Dubins circuit tracked, REGEN/DISCHARGE triggered, telemetry staleness 96 ms | 2026-06-09 |
| Lua script on stock firmware (`src/fc-lua/sitl_lua_test.py`) | 6/6 PASS. Gains scaled at 20k RPM, overspeed and stale-telemetry failsafes | 2026-06-09 |
| Lua script + firmware feed-forward patch (same test, patched SITL) | 7/7 PASS. `FWC: firmware feed-forward active` | 2026-06-09 |
| SITL flight demo (`tools/sitl_fly_demo.py`, checked with `tools/read_last_flight.py`) | Arm, take off, hover, land | 2026-06-10 |
| Pytest suite in CI (`tests/`) | 10 tests: sampler, planner, circuit, windy circuit | 2026-09-24 |

**Known gaps** that SITL cannot close:
- The VESC is still simulated (`VESCInterface(sim=True)`). Regen numbers are estimates.
- `FWC_ACT_NM` is a placeholder (0.8) until measured on the real airframe.

---

## Phase 1 — Mechanical + Basic Flight (Weeks 1–6)

**Goal:** Disc frame flies stably as a conventional quad. No flywheel yet.

### Week 1–2: CAD
- [x] Bottom plate design — v02 generated parametrically, 164 g (was 255 g);
      `tools/generate_cad_v02.py` (2026-06-09)
- [x] Top plate design — v02 R80 electronics tray, 56 g (was 201 g)
- [x] Motor mount pad geometry validated (30×30 pads at R185, 16×16 M3)
- [x] DXF cut profiles exported (`cad/dxf/`) — SendCutSend, CF .118″/.079″
- [ ] Order plates (add fillets in Fusion first; see FRAME_SPEC v02 notes)
- [x] Flywheel rotor STEP exists (`cad/stl/step/flywheel_rotor_v01.step`)
- [ ] Decide rotor: v01 default (I = 1.24e-4) or v02 heavy (I = 1.78e-4).
      v02 means updating the inertia constants listed in STRUCTURE.md
- [ ] Order rotor **and containment cup** from PCBWay CNC (6061-T6), one order
- [ ] Update flywheel boss flange: bolt circle 55 → 62 mm (Fusion)
- [ ] Print landing legs in TPU

### Week 3: Parts arrival + prep
- [ ] Order all Phase 1 electronics (motors, ESC, FC, props, battery)
- [ ] Inspect CF plates for delamination, measure true dimensions
- [ ] Tap M3 holes in carbon fiber (use thread insert or tap carefully)
- [ ] Test fit all components dry (no solder yet)

### Week 4: Assembly
- [ ] Solder ESC stack
- [ ] Mount FC on rubber grommets
- [ ] Install motors, check rotation direction
- [ ] Wire battery leads with XT60
- [ ] Flash ArduCopter 4.5 to H743
- [ ] Initial param config (frame type: X, motor layout)

### Week 5: Ground testing
- [ ] Motor direction test (props off)
- [ ] ESC calibration
- [ ] Accelerometer + compass calibration
- [ ] PID autotune (props on, tethered or on bench stand)
- [ ] Verify no vibration resonance at hover throttle

### Week 6: First flight
- [x] Rehearse arm, takeoff, hover, land in SITL (`tools/sitl_fly_demo.py`, 2026-06-10)
- [ ] Hover test in open area (low altitude, tethered)
- [ ] Validate disc frame CoG in flight
- [ ] Log IMU data — compare vibration profile vs conventional quad
- [ ] Document: does frame show gyroscopic stabilization contribution?

**Phase 1 Exit Criteria:** Stable hover for 5+ minutes, clean IMU logs

---

## Phase 2 — Flywheel Integration (Weeks 7–10)

**Goal:** Flywheel spinning and measurable energy recovery on descent.

### Week 7: Flywheel mechanical
- [ ] Receive machined rotor and containment cup from PCBWay
- [x] Burst containment designed — `containment_cup_v01` (one-piece, 6061;
      see FLYWHEEL_SPEC) — ordered with the rotor in Phase 1
- [ ] Balance rotor (static balance on mandrel)
- [ ] Press-fit angular contact bearings
- [ ] Install flywheel motor (RS2205) into rotor bore
- [ ] Mount assembly on boss, torque retention bolts
- [ ] Spin-pit test per FLYWHEEL_SPEC protocol (cup mandatory) before
      the assembly goes anywhere near the airframe

### Week 8: VESC integration
- [ ] Install VESC Tool on laptop
- [ ] Motor detection wizard (RS2205 on VESC)
- [ ] Configure RPM control mode (target 18,000 RPM initially)
- [ ] Configure regenerative braking limits
- [ ] Bench test: spin up, brake, measure energy returned to bench supply
- [ ] Replace the simulated `VESCInterface` in `momentum_manager.py` with the
      real UART driver, and re-run the SITL test with live VESC data

### Week 9: Gimbal servos
- [ ] Print gimbal brackets (PETG)
- [ ] Install Savöx servos on 2 motor arms
- [ ] Connect to H743 servo outputs
- [ ] Test manual vectoring via RC input

### Week 10: Flight integration
- [ ] Fly with flywheel active (non-regenerative first)
- [ ] Measure hover stability improvement vs Phase 1 logs
- [ ] Enable regen: fly descent profile, log VESC energy counters
- [ ] Calculate actual vs theoretical energy recovery

**Phase 2 Exit Criteria:** Measurable energy recovery on 10m descent profile

---

## Phase 3 — Companion Computer + Pathfinding (Weeks 11–14)

**Goal:** Autonomous arc-path mission with momentum-aware planning.

### Week 11: Companion computer setup
- [ ] Flash Armbian on Orange Pi Zero 3
- [ ] Install MAVProxy + pymavlink
- [ ] Establish UART link to H743 (SERIAL2)
- [ ] Verify telemetry stream in Python on hardware
      (already proven over TCP against SITL; only the UART link is new)

### Week 12: Dubins path implementation
- [x] Implement Dubins path library (inline LSL/RSR/LSR/RSL — no external dep)
- [x] Add momentum constraint: turn radius scales with flywheel charge fraction
- [x] Compute turn radius adjustment from flywheel energy level
- [x] Generate test waypoint set (5-point circuit) — validated in simulation
- [ ] Port to companion computer, query live VESC state via UART

### Week 13: MAVLink integration
- [x] Send Dubins-generated waypoints to ArduCopter via MAVLink — validated in SITL
- [ ] Override default straight-line interpolation
- [x] Test in SITL (Software In The Loop) simulation first — see [SITL_TESTING.md](SITL_TESTING.md)
      (7/7 checks pass: Dubins circuit tracked, REGEN/DISCHARGE state machine
      triggers on real descent/climb, telemetry staleness < 100 ms)
- [ ] Log commanded vs actual path

### Week 14: Full system flight test
- [ ] Fly 5-point mission with arc pathfinding enabled
- [ ] Compare energy consumption vs same mission with straight paths
- [ ] Log: flywheel RPM, VESC energy, battery voltage sag, total flight time
- [ ] Calculate real efficiency gain

**Phase 3 Exit Criteria:** Measurable autonomy improvement in arc vs waypoint mission

---

## Phase 4 — Optimization (Ongoing)

- [x] Firmware gyroscopic feed-forward (AC_AttitudeControl patch + Lua binding,
      validated in patched SITL 2026-06-09 — see src/firmware-patch/)
- [ ] Tune `FWC_ACT_NM` on the real airframe: start at 0.8, compare commanded
      vs achieved rates during flywheel spin-up. Keep `FWC_ENABLE=2` until then
- [ ] Flash the patched firmware to the H743 (currently SITL only)
- [ ] PID retuning with flywheel active (gyroscopic coupling compensation)
- [ ] VESC regen profile optimization per mission type
- [ ] Pathfinding extension: 3D arc paths (altitude changes)
- [ ] Weight reduction iteration (redesign heavy components)
- [ ] Endurance benchmark: timed hover comparison vs equivalent X-quad
- [ ] Consider: paper / technical writeup submission

### Repository health
- [x] Pytest suite (`tests/`) run in CI, plus headless sim run (2026-09-24)
- [x] Planner no longer needs the unbuildable `dubins` C library (2026-09-24)
- [x] MIT LICENSE file added (2026-09-24)
- [x] Unrelated football model moved to its own repository (2026-09-24)
- [ ] Turn the SITL scripts into an opt-in pytest job (needs SITL in CI)
- [ ] Add Lua script unit tests that run without SITL

---

## Milestone Summary

| Milestone | Target Week | Validation | Status (2026-09-24) |
|---|---|---|---|
| Simulation validated | — | Circuit, figure-8, lawnmower, wind + noise | Done 2026-06-09 |
| Flight software validated in SITL | — | 7/7, 6/6, 7/7 test runs + flight demo | Done 2026-06-10 |
| Frame flying stable | 6 | 5min hover, clean logs | Waiting on parts order |
| Flywheel measurable recovery | 10 | VESC energy log on descent | Not started |
| Arc pathfinding operational | 14 | Circuit mission vs waypoint | Proven in SITL, hardware pending |
| Efficiency benchmark | 16 | vs baseline X-quad same motors | Not started |

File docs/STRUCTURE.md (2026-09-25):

# Repository Structure — FlyGimbal

How the repository is laid out, where each piece runs, and which files must
change together. For what the project is, see the [README](../README.md).
For what is done and what is next, see [ROADMAP.md](ROADMAP.md).

---

## Directory Tree

```
FlyGimbal/
├── README.md                         # Project overview, status, quick start
├── LICENSE                           # MIT
├── pitch.md                          # 30-second project pitch
├── requirements.txt                  # Python dependencies (sim, planner, companion, tests)
│
├── .github/
│   ├── workflows/ci.yml              # Planner + headless sim + pytest; docs present and UTF-8
│   ├── ISSUE_TEMPLATE/               # bug_report.md, feature_request.md
│   └── PULL_REQUEST_TEMPLATE.md
│
├── docs/
│   ├── STRUCTURE.md                  # This file
│   ├── ROADMAP.md                    # Phases, progress, validated results
│   ├── PHYSICS.md                    # Gyroscopic stability, FESS, momentum-aware Dubins
│   ├── BOM.md                        # Bill of materials, costs by phase
│   ├── BUILD_GUIDE.md                # Phase 1 assembly steps
│   ├── SITL_TESTING.md               # ArduCopter SITL setup, test procedures, results
│   └── CONTRIBUTING.md               # Branching, commit format, code style
│
├── cad-specs/                        # Design intent: the numbers the geometry must meet
│   ├── FRAME_SPEC.md                 # Disc frame, v01 and v02 plates, CoG targets
│   ├── FLYWHEEL_SPEC.md              # Rotor, bearings, VESC, burst containment
│   └── GIMBAL_SPEC.md                # Thrust-vector servo mounts, ArduCopter config
│
├── cad/                              # Released geometry. See cad/README.md for who makes what
│   ├── README.md                     # Fabrication guide + part inventory
│   ├── preview_assembly.png          # Assembled and exploded prototype render
│   ├── preview_v02.png               # v02 parts render
│   ├── dxf/                          # 2D cut profiles for carbon fiber plates
│   │   ├── frame_bottom_v02.dxf
│   │   └── frame_top_v02.dxf
│   └── stl/                          # Meshes for printing and reference
│       ├── frame_{bottom,top}_v02.stl
│       ├── flywheel_rotor_v01.stl    # Default rotor; software constants match it
│       ├── flywheel_rotor_v02.stl    # Optional heavy rotor
│       ├── flywheel_boss_v01.stl
│       ├── containment_cup_v01.stl
│       ├── gimbal_{servo_mount,motor_plate}_v01.stl
│       ├── vesc_mount_bracket_v01.stl
│       ├── landing_leg_v01.stl
│       ├── v01/                      # Superseded v01 frame plates
│       └── step/                     # STEP solids for CNC quoting (same parts)
│           ├── v01/                  # Superseded v01 frame plates
│           ├── preview/parts_sheet.svg
│           └── frame_preview.svg
│
├── src/
│   ├── simulation/
│   │   └── gyrodrone_sim.py          # 6-DOF physics sim: flywheel, gimbals, wind, noise
│   ├── pathfinding/
│   │   └── dubins_momentum.py        # Momentum-aware Dubins planner + MAVLink upload
│   ├── momentum-manager/
│   │   ├── momentum_manager.py       # Companion-computer daemon: flywheel modes, FC link
│   │   └── sitl_test.py              # 7-check integration test against ArduCopter SITL
│   ├── fc-lua/
│   │   ├── flywheel_coupling.lua     # Flight-controller script: gain scheduling, failsafes
│   │   └── sitl_lua_test.py          # SITL test for the Lua script
│   └── firmware-patch/
│       ├── README.md                 # What the patch changes and how to build it
│       ├── apply_patch.py            # Anchored, idempotent patch applier
│       ├── flywheel_ff.patch         # Exact validated diff (ArduPilot @ 1b7d3cde)
│       └── build_sitl.sh             # Patch, build and stage a SITL binary in WSL
│
├── tools/
│   ├── generate_cad_v02.py           # Parametric v02 part generator (CadQuery)
│   ├── render_assembly.py            # Renders cad/preview_assembly.png from the STLs
│   ├── stl_check.py                  # Mass and inertia audit of STL files
│   ├── sitl_fly_demo.py              # SITL demo: arm, take off, hover, land
│   └── read_last_flight.py           # Summarizes the last SITL DataFlash log
│
└── tests/
    └── test_smoke.py                 # Dubins sampler, planner, full sim missions (pytest)
```

The simulator keeps its original file name, `gyrodrone_sim.py`. GyroDrone was
the project's working name. Other scripts import the simulator by that name,
so it was not renamed.

---

## Where Each Piece Runs

| Layer | Hardware | Code | Talks to |
|---|---|---|---|
| Design and validation | Laptop | `src/simulation/`, `tools/`, `tests/` | Nothing. Runs offline |
| Companion computer | Orange Pi Zero 3 | `src/momentum-manager/`, `src/pathfinding/` | FC over MAVLink UART. VESC over UART |
| Flight controller script | Matek H743, ArduCopter 4.5+ | `src/fc-lua/flywheel_coupling.lua` | Companion, via the `FWRPM` MAVLink value |
| Flight controller firmware | Matek H743 | `src/firmware-patch/` applied to ArduPilot | Lua script, via `set_flywheel_momentum()` |
| Flywheel speed controller | VESC | Configured in VESC Tool (see FLYWHEEL_SPEC) | Companion over UART |

Before hardware exists, ArduCopter SITL running in WSL stands in for the
flight controller. The VESC is still simulated inside `momentum_manager.py`.

### Data Flow in Flight

```
VESC ──UART──► momentum_manager.py ──MAVLink "FWRPM"──► flywheel_coupling.lua
                      │                                        │
                      │ Dubins path points                     │ H = I·ω, ~10 Hz
                      ▼                                        ▼
               ArduCopter GUIDED mode ◄──── patched rate loop adds H × gyro at 400 Hz
```

---

## Files That Must Change Together

| If you change | Also update |
|---|---|
| Flywheel rotor geometry or inertia | `FW_I` in the sim, `FLYWHEEL_I` in the momentum manager, `self.I` in the planner, the `FWC_INERTIA` default in the Lua script, FLYWHEEL_SPEC |
| Airframe mass | The component masses behind `MASS` in the sim, `DRONE_MASS_KG` in the momentum manager and the planner, FRAME_SPEC |
| v02 part dimensions | Edit `tools/generate_cad_v02.py` and re-run it. Never edit the exported STL, STEP or DXF files by hand |
| Released STLs | Re-run `tools/render_assembly.py` and `tools/stl_check.py`, then update the cad/README inventory |
| ArduPilot version | Re-run `apply_patch.py` and regenerate `flywheel_ff.patch` |
| Validated controller gains | The controller parameter block in ROADMAP.md |

---

## Conventions

- **Frames.** Simulation and MAVLink targets use NED. Flywheel spin axis is body Z.
- **Units.** SI throughout. Headings are degrees in waypoint lists and radians inside planners.
- **Versions.** Parts carry a `_vNN` suffix. Superseded versions move to a `v01/` subfolder.
- **Generated files.** STL, STEP and DXF are ignored by git everywhere except under `cad/`.
- **Encoding.** All Markdown is UTF-8. CI fails on any other encoding.

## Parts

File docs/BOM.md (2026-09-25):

# Bill of Materials — FlyGimbal v0.1

> All prices in USD. Sourced May 2025. Prices subject to change.

---

## Phase 1 — Frame + Basic Flight (~$200)

| # | Component | Model | Qty | Unit $ | Total $ | Source |
|---|---|---|---|---|---|---|
| 1 | Frame — bottom plate (3mm CF) | Custom CNC | 1 | 35 | 35 | PCBWay / SendCutSend |
| 2 | Frame — top plate (2mm CF) | Custom CNC | 1 | 25 | 25 | PCBWay / SendCutSend |
| 3 | Main motors | EMAX ECO II 2807 1300KV | 4 | 15 | 60 | GetFPV / Amazon |
| 4 | ESC 4-in-1 stack | Tekko32 F4 35A | 1 | 42 | 42 | GetFPV |
| 5 | Flight controller | Matek H743-SLIM | 1 | 60 | 60 | mateksys.com |
| 6 | Propellers | HQProp 9×4.5 3-blade | 4 pairs | 3 | 12 | HQProp |
| 7 | Battery (main) | CNHL 4S 3000mAh 100C | 1 | 30 | 30 | Amazon |
| 8 | RC receiver | ExpressLRS EP1 (2.4GHz) | 1 | 12 | 12 | Airbot / Banggood |
| 9 | Standoffs M3×20mm (Al) | Generic | 8 | — | 4 | Amazon |
| 10 | Hardware kit (screws, nuts) | M2/M3 assorted | 1 set | 8 | 8 | Amazon |
| **Phase 1 Total** | | | | | **~$288** | |

---

## Phase 2 — Flywheel + Gimbal (~$130)

| # | Component | Model | Qty | Unit $ | Total $ | Source |
|---|---|---|---|---|---|---|
| 11 | Flywheel rotor | Custom Al 6061 CNC | 1 | 30 | 30 | PCBWay CNC |
| 12 | Flywheel motor | Emax RS2205 2300KV | 1 | 15 | 15 | GetFPV |
| 13 | Flywheel ESC | VESC 4.12 | 1 | 40 | 40 | VESC Project / Flipsky |
| 14 | Bearings (deep groove, C3) | SKF 6000-2RS C3 — 10×26×8mm, 20g each | 2 | 10 | 20 | Amazon / SKF distributor |
| 15 | Flywheel battery | 2S 1000mAh LiPo | 1 | 12 | 12 | Amazon |
| 16 | Gimbal servos | Savöx SH-0257MG | 2 | 18 | 36 | Servo City / Amazon |
| 17 | Gimbal bracket | Custom PETG print | 2 | — | 4 (filament) | Local print |
| 18 | Flywheel mount boss | Custom PETG print | 1 | — | 2 (filament) | Local print |
| **Phase 2 Total** | | | | | **~$159** | |

---

## Phase 2a — Full Prototype, All-at-Once (~$447)

> **Alternative to Phases 1 + 2 combined.** Order everything below in a single pass and build the complete gyroscopic prototype without waiting for a Phase 1 flight-test milestone. Same total cost — benefit is fewer shipping runs and no component trickle-in delays.
>
> **No true duplicates exist between Phases 1 and 2.** The two ESCs serve different motors (Tekko32 → quad, VESC → flywheel). The two batteries are on different voltage rails (4S → main motors, 2S → flywheel VESC) and cannot be merged without a redesign. Hardware kit (item 10) covers both frame and gimbal assembly.

| # | Component | Model | Qty | Unit $ | Total $ | Source |
|---|---|---|---|---|---|---|
| 1 | Frame — bottom plate (3mm CF) | Custom CNC | 1 | 35 | 35 | PCBWay / SendCutSend |
| 2 | Frame — top plate (2mm CF) | Custom CNC | 1 | 25 | 25 | PCBWay / SendCutSend |
| 3 | Main motors | EMAX ECO II 2807 1300KV | 4 | 15 | 60 | GetFPV / Amazon |
| 4 | ESC 4-in-1 stack (quad) | Tekko32 F4 35A | 1 | 42 | 42 | GetFPV |
| 5 | Flight controller | Matek H743-SLIM | 1 | 60 | 60 | mateksys.com |
| 6 | Propellers | HQProp 9×4.5 3-blade | 4 pairs | 3 | 12 | HQProp |
| 7 | Flight battery | CNHL 4S 3000mAh 100C | 1 | 30 | 30 | Amazon |
| 8 | RC receiver | ExpressLRS EP1 (2.4GHz) | 1 | 12 | 12 | Airbot / Banggood |
| 9 | Standoffs M3×20mm (Al) | Generic | 8 | — | 4 | Amazon |
| 10 | Hardware kit (screws, nuts) | M2/M3 assorted — covers frame + gimbal | 1 set | 8 | 8 | Amazon |
| 11 | Flywheel rotor | Custom Al 6061 CNC | 1 | 30 | 30 | PCBWay CNC |
| 12 | Flywheel motor | Emax RS2205 2300KV | 1 | 15 | 15 | GetFPV |
| 13 | Flywheel ESC (VESC) | VESC 4.12 | 1 | 40 | 40 | VESC Project / Flipsky |
| 14 | Bearings (deep groove, C3) | SKF 6000-2RS C3 — 10×26×8mm, 20g each | 2 | 10 | 20 | Amazon / SKF distributor |
| 15 | Flywheel battery | 2S 1000mAh LiPo | 1 | 12 | 12 | Amazon |
| 16 | Gimbal servos | Savöx SH-0257MG | 2 | 18 | 36 | Servo City / Amazon |
| 17 | Gimbal bracket | Custom PETG print | 2 | — | 4 (filament) | Local print |
| 18 | Flywheel mount boss | Custom PETG print | 1 | — | 2 (filament) | Local print |
| **Phase 2a Total** | | | | | **~$447** | |

---

## Phase 3 — Companion Computer + Sensing (~$55)

| # | Component | Model | Qty | Unit $ | Total $ | Source |
|---|---|---|---|---|---|---|
| 19 | Companion computer | Orange Pi Zero 3 (1GB) | 1 | 20 | 20 | Orange Pi official |
| 20 | External IMU | ICM-42688-P breakout | 1 | 15 | 15 | Adafruit / SparkFun |
| 21 | UART cable (FC↔Pi) | JST-GH 4-pin | 2 | 3 | 6 | Amazon |
| 22 | MicroSD (OS) | SanDisk 32GB A1 | 1 | 8 | 8 | Amazon |
| 23 | Rubber grommets M2.5 | IMU isolation | 6 | — | 3 | Amazon |
| **Phase 3 Total** | | | | | **~$52** | |

---

## Phase 4A — Terrain Following / Precision Landing (~$26)

> Single downward-facing rangefinder. Enables terrain following, altitude hold independent of GPS, and precision landing. ArduPilot native — set `RNGFND1_TYPE=20`, `RNGFND1_ORIENT=25` (down).

| # | Component | Model | Qty | Unit $ | Total $ | Source |
|---|---|---|---|---|---|---|
| 24 | Downward rangefinder | Benewake TFmini-S | 1 | 25 | 25 | Amazon / Benewake |
| 25 | Sensor mount | Custom PETG print (downward bracket) | 1 | — | 1 (filament) | Local print |
| **Phase 4A Total** | | | | | **~$26** | |

---

## Phase 4B — Echolocation Array / Obstacle Avoidance (~$98)

> Five TF-Luna sensors arranged radially (front, rear, left, right, down) — the drone maps its surroundings in 360°, like whale echolocation. Requires the Orange Pi companion (Phase 3) or direct I2C to FC via multiplexer. ArduPilot `PRX_TYPE=4` (proximity) enables automatic obstacle avoidance in LOITER and AUTO modes.

| # | Component | Model | Qty | Unit $ | Total $ | Source |
|---|---|---|---|---|---|---|
| 26 | Proximity rangefinders | Benewake TF-Luna (8m, I2C) | 5 | 18 | 90 | Amazon / Benewake |
| 27 | I2C multiplexer | TCA9548A breakout | 1 | 5 | 5 | Adafruit / Amazon |
| 28 | Radial sensor mounts | Custom PETG print (×5 brackets) | 1 set | — | 3 (filament) | Local print |
| **Phase 4B Total** | | | | | **~$98** | |

> **Note:** Phase 4B replaces Phase 4A's downward sensor — the TF-Luna pointed down covers terrain following too. Don't buy both; go 4A first to validate ArduPilot rangefinder config, then upgrade to 4B.

---

## Miscellaneous / Consumables

| Item | Est. Cost |
|---|---|
| Heat shrink assorted | $5 |
| 16AWG / 20AWG wire (1m each) | $6 |
| XT60 connectors (2 pairs) | $4 |
| JST-PH connectors assorted | $4 |
| Loctite 243 (threadlocker) | $8 |
| CA glue + accelerator | $6 |
| Kapton tape | $3 |
| Cable ties 2.5mm | $3 |
| **Misc Total** | **~$39** |

---

## Grand Total by Phase

### Path A — Incremental (Phases 1 → 2 → 3 → 4)

| Phase | Component Scope | Cost |
|---|---|---|
| Phase 1 | Frame + basic flight | ~$288 |
| Phase 2 | Flywheel + gimbal (add-on) | ~$159 |
| Phase 3 | Companion + IMU | ~$52 |
| Phase 4A | Terrain following (single sonar) | ~$26 |
| Phase 4B | Echolocation array (upgrade) | ~$98 |
| Misc | Consumables | ~$39 |
| **GRAND TOTAL (4A only)** | | **~$662** |
| **GRAND TOTAL (full 4B)** | | **~$736** |

### Path B — Prototype First (Phase 2a → Phase 3 → 4)

| Phase | Component Scope | Cost |
|---|---|---|
| Phase 2a | Full prototype all-at-once | ~$447 |
| Phase 3 | Companion + IMU | ~$52 |
| Phase 4A | Terrain following (single sonar) | ~$26 |
| Phase 4B | Echolocation array (upgrade) | ~$98 |
| Misc | Consumables | ~$39 |
| **GRAND TOTAL (4A only)** | | **~$662** |
| **GRAND TOTAL (full 4B)** | | **~$736** |

> Same total cost either path through Phase 3. Phase 2a trades incremental validation for faster assembly. Phase 4B replaces 4A — don't stack both.

> ⚠️ Slightly over the $500 target. Cost reduction options:
> - Use AliExpress for motors (-$20): EMAX ECO II available ~$11/unit
> - PCBWay for CF frame vs SendCutSend (-$15)
> - Skip Phase 2 gimbal servos for initial hover validation (-$36, re-add before flywheel test)
> - **Adjusted Phase 1 only: ~$270** ← lowest-risk start

---

## Supplier Reference

| Supplier | Best For | Shipping |
|---|---|---|
| GetFPV.com | Motors, ESCs, FC | US, 2–5 days |
| mateksys.com | Matek FC direct | Ships from HK, 10–15 days |
| PCBWay.com | CNC + CF plates | 10–15 days |
| SendCutSend.com | CF/Al sheet cutting | US, 3–5 days |
| Amazon | Bearings, hardware, misc | Prime 1–2 days |
| Flipsky.net | VESC variants | 7–14 days |
| HQProp.com | Propellers | 7–10 days |
| Orange Pi (official) | Orange Pi Zero 3 | 2–3 weeks |

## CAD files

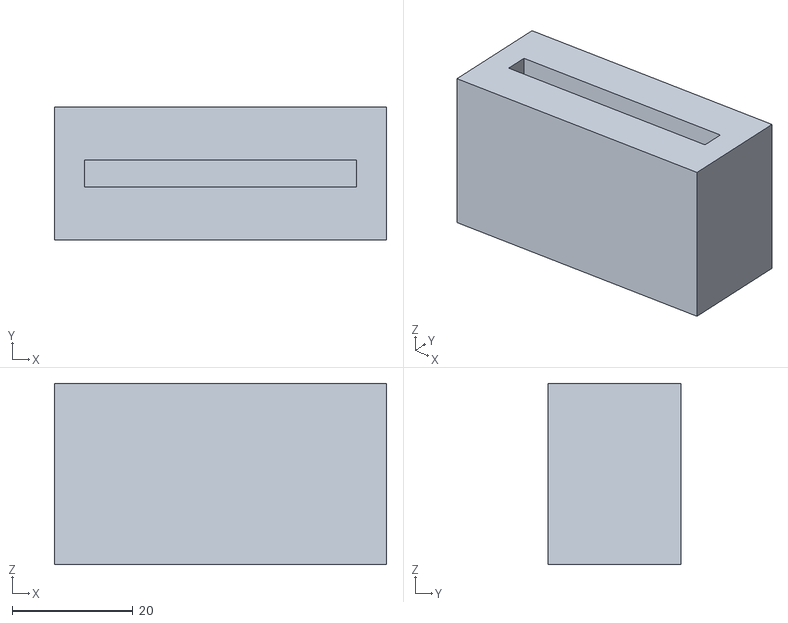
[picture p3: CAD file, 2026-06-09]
cad/stl/landing_leg_v01.stl
55.0 x 22.0 x 30.0

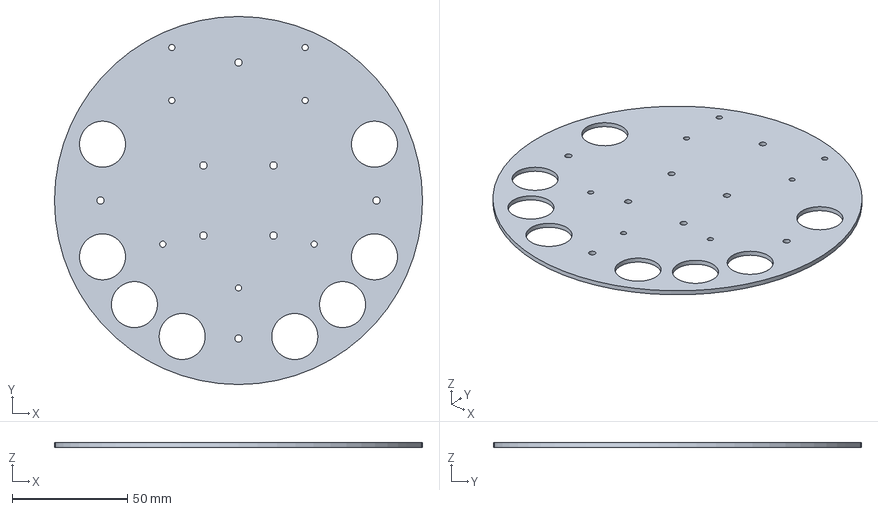
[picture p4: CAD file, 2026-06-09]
cad/stl/step/frame_top_v02.step
160.0 x 160.0 x 2.00 mm

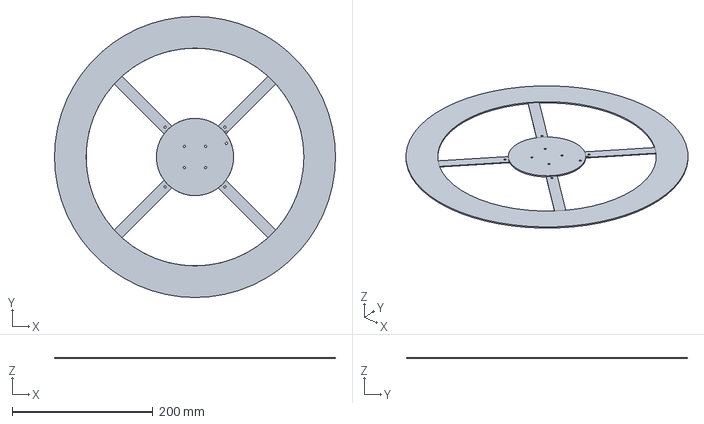
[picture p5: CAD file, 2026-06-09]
cad/stl/step/v01/frame_top_v01.step
400.0 x 400.0 x 2.00 mm

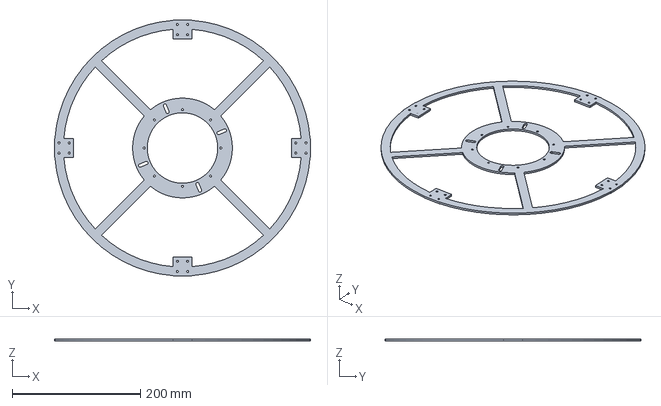
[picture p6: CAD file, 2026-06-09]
cad/stl/step/frame_bottom_v02.step
400.0 x 400.0 x 3.00 mm

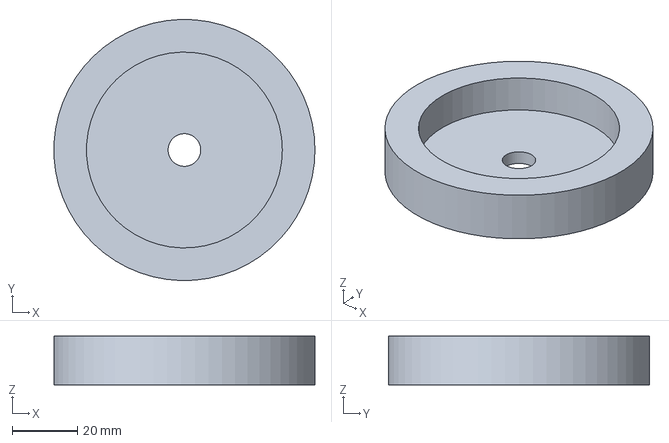
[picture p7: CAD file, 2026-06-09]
cad/stl/step/v01/flywheel_rotor_v01.step
79.9 x 80.0 x 15.0 mm

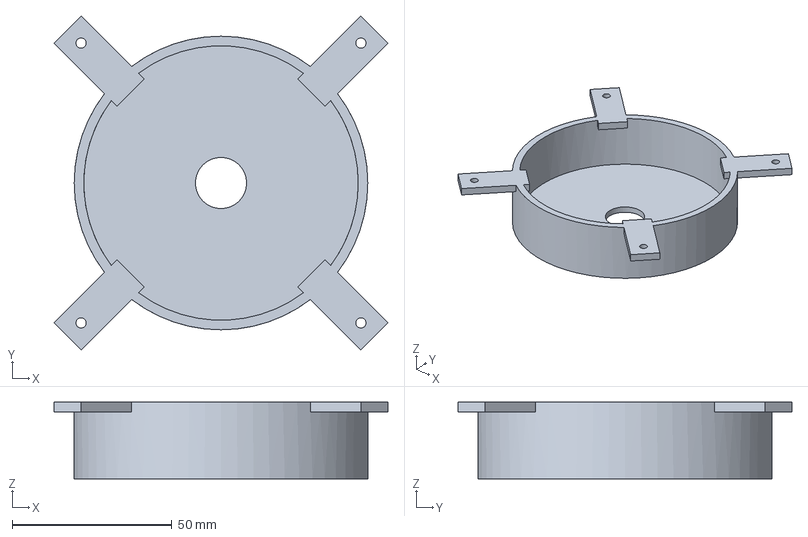
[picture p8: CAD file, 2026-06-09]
cad/stl/step/containment_cup_v01.step
104.7 x 104.7 x 24.0 mm

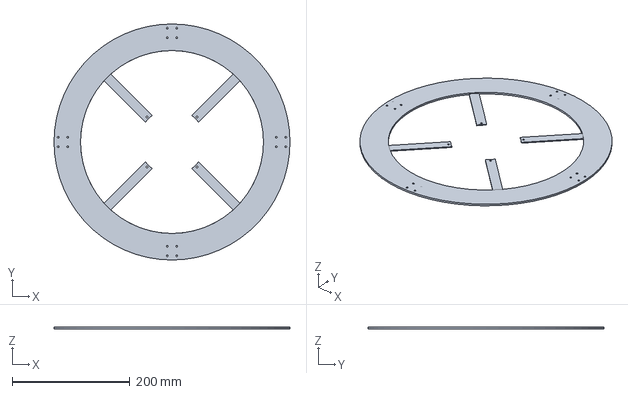
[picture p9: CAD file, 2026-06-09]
cad/stl/step/v01/frame_bottom_v01.step
400.0 x 400.0 x 3.00 mm

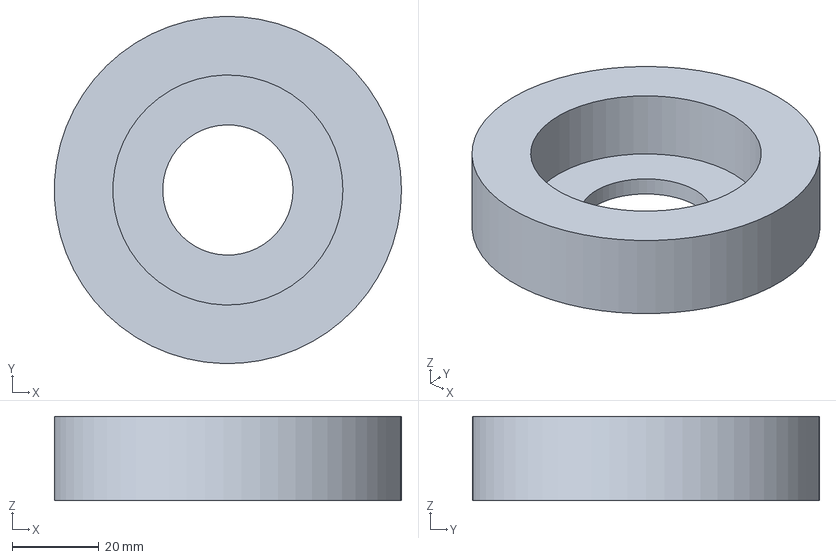
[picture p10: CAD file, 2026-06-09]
cad/stl/step/flywheel_rotor_v02.step
79.9 x 80.0 x 19.4 mm

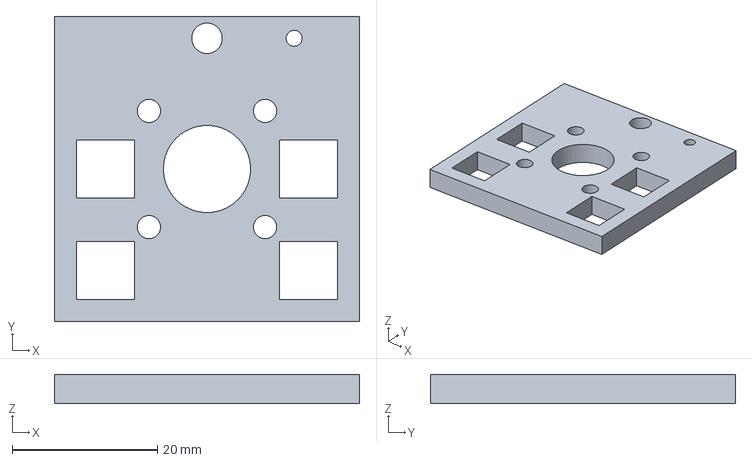
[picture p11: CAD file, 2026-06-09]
cad/stl/step/gimbal_motor_plate_v01.step
42.0 x 42.0 x 4.00 mm

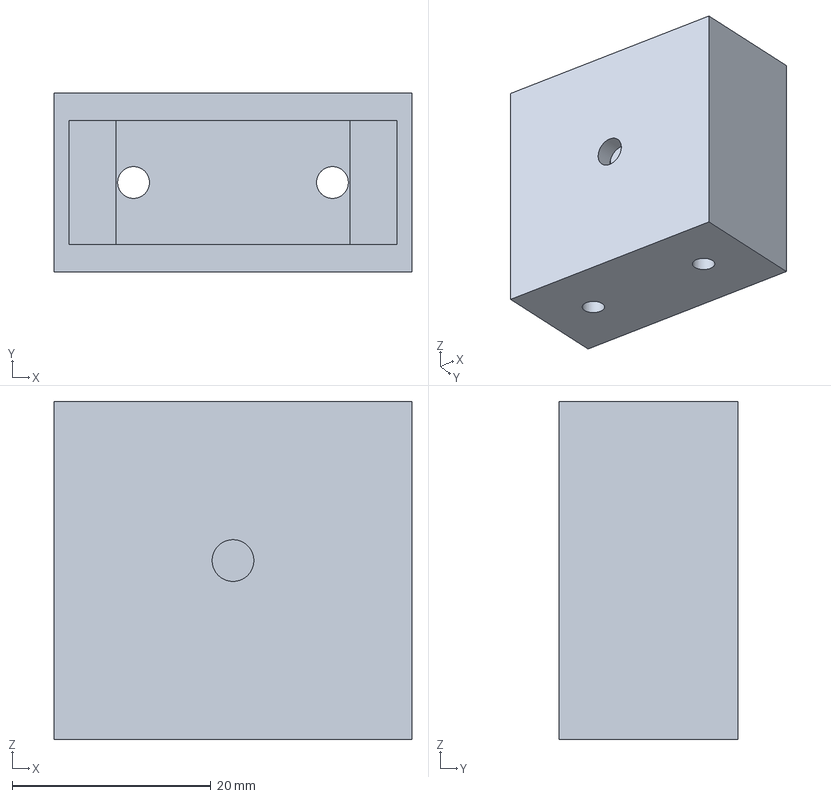
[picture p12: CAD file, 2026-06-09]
cad/stl/step/gimbal_servo_mount_v01.step
36.0 x 18.0 x 34.0 mm

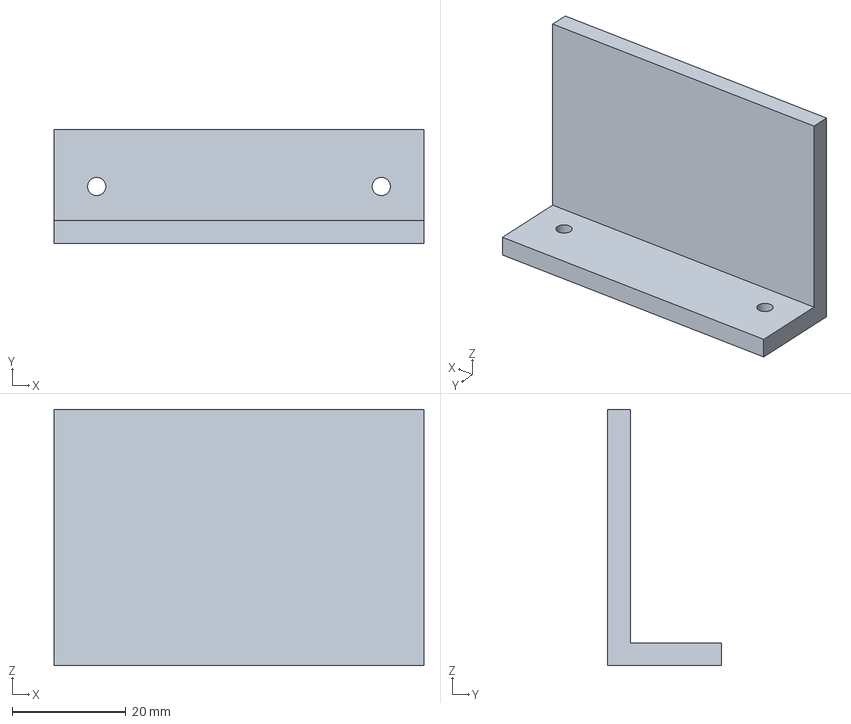
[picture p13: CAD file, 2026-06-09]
cad/stl/step/vesc_mount_bracket_v01.step
65.0 x 20.0 x 45.0 mm

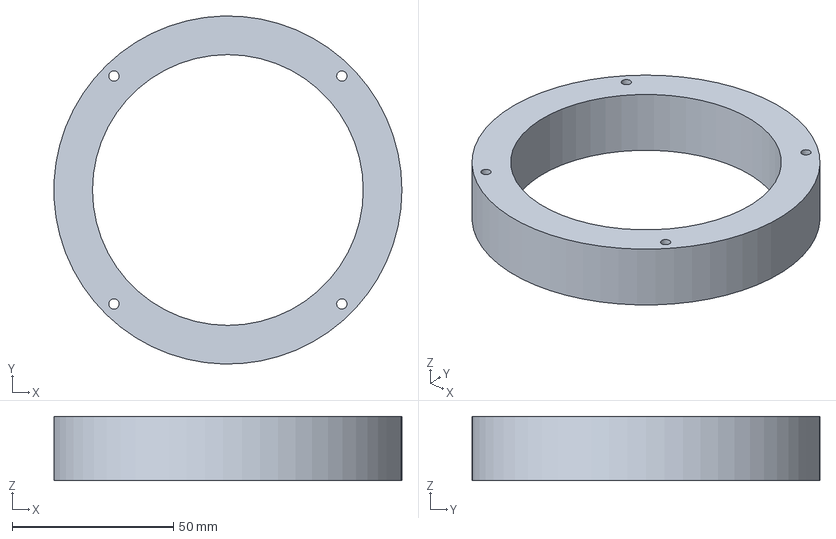
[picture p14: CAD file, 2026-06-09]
cad/stl/step/flywheel_boss_v01.step
107.9 x 108.0 x 20.0 mm

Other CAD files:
cad/dxf/frame_bottom_v02.dxf
cad/dxf/frame_top_v02.dxf
cad/stl/containment_cup_v01.stl
cad/stl/flywheel_boss_v01.stl
cad/stl/flywheel_rotor_v01.stl
cad/stl/flywheel_rotor_v02.stl
cad/stl/frame_bottom_v02.stl
cad/stl/frame_top_v02.stl
cad/stl/gimbal_motor_plate_v01.stl
cad/stl/gimbal_servo_mount_v01.stl
cad/stl/v01/flywheel_rotor_v01.stl
cad/stl/v01/frame_bottom_v01.stl
cad/stl/v01/frame_top_v01.stl
cad/stl/vesc_mount_bracket_v01.stl

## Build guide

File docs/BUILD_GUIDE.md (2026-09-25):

# Build Guide — FlyGimbal Phase 1

> Step-by-step assembly for the disc frame + basic flight.
> Assumes engineer-level electronics experience.

---

## Tools Required

- Soldering iron (fine tip, 350°C)
- M2/M3 hex drivers (ball-end preferred for CF)
- Digital calipers
- Multimeter
- Threadlocker (Loctite 243)
- Heat gun or lighter (heat shrink)
- Laptop with Betaflight Configurator + Mission Planner installed
- USB-C cable
- 3–4mm CF drill bit (carbide, NOT HSS — CF destroys steel bits fast)

---

## Step 1 — Inspect Frame Plates

When CF plates arrive from PCBWay/SendCutSend:

1. Verify all dimensions with calipers — critical: motor mount holes must be at exactly 185mm from center
2. Check for delamination at edges — run finger along all cut edges
3. Sand all cut edges with 220-grit (CF edge dust is sharp and slightly hazardous — wear mask)
4. Test fit motor mounts — bolt pattern should align without stress

> ⚠️ Carbon fiber dust is a lung irritant. Sand/drill only with N95 mask and outdoors or with dust extraction.

---

## Step 2 — Drill and Tap Motor Mount Holes

CF plates typically arrive with holes. Verify:

1. Motor mount: 4× M3 holes per position, 16mm × 16mm pattern
2. FC/ESC stack: 30.5mm × 30.5mm, center of top plate
3. Standoff holes: M3, at 60mm radius on bottom plate

If holes need enlarging: use carbide bit at low speed, high pressure. CF doesn't drill like metal — let the bit cut, don't force it.

Do NOT tap CF threads — use M3 nyloc nuts on the back side, or press-in threaded inserts (M3 brass heat inserts work well with CF via CA glue, not heat).

---

## Step 3 — Install Standoffs

Bottom plate:
1. Insert M3 × 20mm aluminum standoffs through bottom plate holes
2. Secure with M3 nyloc nuts on the underside — no Loctite needed (nyloc sufficient)
3. Check standoffs are perpendicular to plate surface (use square)

---

## Step 4 — Solder ESC Stack

4-in-1 ESC stack (Tekko32 35A):

1. Pre-tin all pads before connecting anything
2. Main power leads: 16AWG, short as possible (<80mm)
3. Solder XT60 female connector to battery input pads
4. Motor phase wires: 20AWG, route through frame arm channels
5. Add capacitor (1000µF 35V electrolytic) across battery pads — reduces voltage spikes
6. Check: no solder bridges, no cold joints

**Motor direction wiring:**
Standard quad layout — verify with ArduCopter motor diagram for your frame type.
Incorrect direction fixed in software (BLHELI_32 direction reversal) — don't re-solder.

---

## Step 5 — Mount FC

Matek H743-SLIM on top plate:

1. Install M3 rubber grommets in FC mount holes
2. FC sits on grommets (vibration isolation — critical)
3. FC orientation: arrow pointing FORWARD (to front of disc)
4. Connect ESC stack to FC:
   - UART for DSHOT telemetry
   - 4× signal wires (DSHOT600 to ESC inputs)
   - 5V BEC from ESC to FC power input
5. Confirm FC is NOT touching any carbon fiber directly (shorts risk)

---

## Step 6 — Install Motors

At each of the 4 motor mount positions:

1. Place 1.5mm neoprene washer between motor base and CF pad
2. Insert motor, align bolt holes
3. Apply small drop Loctite 243 to M3 motor bolts
4. Torque to 0.5 N·m (snug, not gorilla-tight — CF strips)
5. Route motor phase wires through nearest slot in ring

**Check:** Spin each motor by hand after mounting — should spin freely with no binding or grinding. Any roughness = bearing issue, return the motor.

---

## Step 7 — Install RC Receiver

ExpressLRS EP1 receiver:

1. Bind receiver to transmitter first (bench, before installing)
2. Mount with double-sided tape on top plate, antenna oriented vertically
3. Connect: UART2 on H743 (TX2/RX2 pads)
4. In ArduCopter: SERIAL2_PROTOCOL = 23 (CRSF/ELRS)

---

## Step 8 — Flash ArduCopter

1. Download ArduCopter 4.5+ for MatekH743
2. Flash via Mission Planner: Initial Setup → Install Firmware → Load custom firmware
3. After flash, DO NOT set any params yet — let it boot clean

---

## Step 9 — Initial Configuration (Mission Planner)

```
Frame setup:
  FRAME_CLASS = 1 (Quad)
  FRAME_TYPE  = 1 (X)

Motor test (props OFF):
  Mission Planner → Optional Hardware → Motor Test
  Verify: A=front-right, B=rear-right, C=rear-left, D=front-left
  Correct direction in BLHeli_32 Configurator if needed

Accelerometer calibration:
  Initial Setup → Mandatory Hardware → Accel Calibration
  Follow 6-position sequence

Compass calibration:
  Initial Setup → Mandatory Hardware → Compass
  Rotate drone in all axes until complete

RC calibration:
  Radio Calibration → move all sticks to extremes

Flight modes:
  Ch5: Stabilize / AltHold / Loiter
```

---

## Step 10 — Pre-flight Checks

Before first flight, verify:

- [ ] All motor bolts Loctited and torqued
- [ ] Props installed correct direction (check blade pitch angle)
- [ ] Props tight on motor shafts (M5 bolt + washer)
- [ ] Battery lead polarity verified with multimeter BEFORE connecting battery
- [ ] No exposed wire near props arc
- [ ] FC armed/disarmed LED behavior correct
- [ ] Throttle failsafe set (loss of signal → disarm or land)
- [ ] Geofence set to 30m radius for first test

---

## Step 11 — First Hover (Tethered Recommended)

1. Outdoor open area, calm wind
2. Tie 4 light tethers (~2m) at motor arm tips to ground stakes
3. Arm and throttle up slowly to hover point
4. Observe: any oscillation? Any unusual vibration?
5. If oscillating: reduce P gains (Roll/Pitch P by 20%)
6. Hover 30 seconds, disarm, inspect: any loose screws? Motor heat?
7. Check ArduCopter logs for vibration levels (should be <15 m/s² noise)

---

## Phase 1 Complete When:

- [ ] Stable 5-minute hover
- [ ] Accel noise <15 m/s² in logs  
- [ ] No heating issues (motors <60°C after 5min)
- [ ] Control response feels normal in Stabilize mode
- [ ] Ready to proceed to Phase 2 (flywheel installation)

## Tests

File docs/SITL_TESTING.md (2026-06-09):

# SITL Integration Testing — Momentum Manager

Validates `src/momentum-manager/momentum_manager.py` against a **real ArduCopter
SITL** (Software In The Loop) instance before any hardware exists. The test
flies a full mission — takeoff, Dubins circuit, descent (REGEN), climb
(DISCHARGE), land — while the MomentumManager consumes live MAVLink telemetry.

## What it validates

| Check | Why it matters |
|---|---|
| FCInterface connects to real MAVLink | Catches connection-string / heartbeat bugs the internal sim hides |
| Dubins circuit tracked (33 points) | Guided-mode position targets work end-to-end |
| REGEN triggers on real descent | The vz sign convention and state machine survive a real EKF |
| DISCHARGE triggers on real climb | Same, ascending branch |
| Telemetry staleness < 0.5 s | Verifies the message-drain loop keeps up with stream rates |
| Mode decoded from heartbeat | `telem.mode` reads `"GUIDED"`, not `"UNKNOWN"` |
| Altitude agreement | GLOBAL_POSITION_INT scaling is correct |

Last full run (2026-06-09): **7/7 PASS**, max telemetry staleness 96 ms,
33/33 path points captured.

## Setup (Windows + WSL2)

The prebuilt SITL binary runs in WSL; the test runs on Windows and connects
over localhost (WSL2 forwards the ports automatically).

```bash
# Inside WSL (one-time)
mkdir -p ~/sitl && cd ~/sitl
curl -sL -o arducopter https://firmware.ardupilot.org/Copter/stable/SITL_x86_64_linux_gnu/arducopter
curl -sL -o copter.parm https://raw.githubusercontent.com/ArduPilot/ardupilot/master/Tools/autotest/default_params/copter.parm
chmod +x arducopter
```

## Running the test

**Terminal 1 — SITL (keep this window open):**

```bash
wsl -e bash -c "cd ~/sitl && rm -f eeprom.bin && exec ./arducopter -w --model + --speedup 2 --defaults copter.parm --home -35.363261,149.165230,584,353"
```

**Terminal 2 — test (Windows):**

```powershell
.venv\Scripts\pip install pymavlink        # one-time
.venv\Scripts\python src\momentum-manager\sitl_test.py
```

Takes ~3 minutes. Exits 0 on all-pass, 1 on any failure.

## Gotchas (learned the hard way)

1. **Don't detach SITL inside WSL** (`nohup`/`setsid` + closing the session).
   WSL2 tears down the VM when the launching `wsl.exe` exits, killing SITL
   silently. Keep a foreground `wsl.exe` alive for the duration.
2. **Don't port-probe 5760.** SITL's SERIAL0 exits when its first TCP client
   disconnects. The test itself must be the first connection.
3. **Two MAVLink clients need two ports.** The test commands on `tcp:5760`
   (SERIAL0); the MomentumManager's FCInterface listens on `tcp:5762`
   (SERIAL1). SERIAL1 only binds after SERIAL0 has a client.
4. The test sets `ARMING_CHECK=0` and `FS_THR_ENABLE=0` because no RC is
   attached. **Bench config only — never on real hardware.**

## Lua applet test — flywheel coupling mitigation

`src/fc-lua/flywheel_coupling.lua` runs **on the flight controller**. On stock
firmware it provides gain-scheduling mitigation; on patched firmware (see
below) it additionally drives true rate-loop feed-forward. The applet:

- receives flywheel RPM from the companion (`NAMED_VALUE_FLOAT "FWRPM"`,
  broadcast at 5 Hz by `momentum_manager.py`)
- gain-schedules `ATC_RAT_RLL/PIT` P+D up to `FWC_SCL_MAX` (default 1.25×)
  at full RPM — runtime-only writes, no flash wear
- warns the GCS on overspeed, reverts gains if RPM telemetry goes stale

Validate it against SITL (script must be in `~/sitl/scripts/` before launch):

```powershell
wsl -e bash -lc "mkdir -p ~/sitl/scripts && cp /mnt/d/Projects/Python/FlyGimbal/src/fc-lua/flywheel_coupling.lua ~/sitl/scripts/"
# start SITL (terminal 1, as above), then:
.venv\Scripts\python src\fc-lua\sitl_lua_test.py
```

Last run (2026-06-09): **6/6 PASS** — gains scaled 0.135→0.169 at 20k RPM,
overspeed + stale-failsafe messages confirmed.

Implementation note: `mavlink:receive_chan()` delivers a serialized
`mavlink_message_t` struct (checksum@1, magic@3, msgid u24@10, payload@13),
NOT raw wire bytes. Parsing it as wire format fails silently.

## Patched firmware test — true gyroscopic feed-forward

The `tau_roll += H*q; tau_pitch -= H*p` term validated in `gyrodrone_sim.py`
is now available as a real firmware patch — see
[src/firmware-patch/README.md](../src/firmware-patch/README.md). The Lua applet
auto-detects it: on patched builds it announces
`FWC: firmware feed-forward active` and pushes live `H = I·ω` into the rate
loop; on stock builds it announces `FWC: stock firmware, gain scheduling only`
and falls back gracefully.

Build + validate (WSL):

```bash
bash /mnt/d/Projects/Python/FlyGimbal/src/firmware-patch/build_sitl.sh
# launch ~/sitl-patched/arducopter (same launch command, cd ~/sitl-patched), then:
# .venv\Scripts\python src\fc-lua\sitl_lua_test.py        (from Windows)
```

Last run (2026-06-09, ArduPilot master @ 1b7d3cde): **7/7 PASS** — including
`FWC: firmware feed-forward active`, and the stale-telemetry failsafe zeroing
the feed-forward (`set_flywheel_momentum(0)`) alongside the gain revert.

To verify the stock-firmware fallback path instead, run the same test against
the unpatched binary with `--stock`.

## Known sim-vs-real gaps this does NOT cover

- The VESC side is still simulated (`VESCInterface(sim=True)`) — regen/assist
  joule numbers are bookkeeping estimates, not physics.
- `FWC_ACT_NM` (actuator output per N·m) is a placeholder (0.8) until measured
  on the real airframe — SITL confirms the plumbing, not the scaling.

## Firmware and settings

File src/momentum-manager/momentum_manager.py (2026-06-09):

"""
FlyGimbal — Momentum Manager
src/momentum-manager/momentum_manager.py

Central coordinator between:
  - Flywheel state (VESC telemetry)
  - Flight controller (MAVLink)
  - Path planner (Dubins)
  - Energy budget decisions

Runs on companion computer (Orange Pi Zero 3).
Communicates with H743 via UART/MAVLink and VESC via UART.

Dependencies:
    pip install pymavlink numpy pyserial

Usage:
    python momentum_manager.py --fc /dev/ttyS1 --vesc /dev/ttyS3
    python momentum_manager.py --sim   # full simulation, no hardware
"""

import time
import math
import threading
import logging
import argparse
from dataclasses import dataclass, field
from enum import Enum, auto
from collections import deque
from typing import Optional

try:
    from pymavlink import mavutil
except ImportError:
    mavutil = None

try:
    import serial
except ImportError:
    serial = None

import numpy as np

# ─── Logging ──────────────────────────────────────────────────────────────────

logging.basicConfig(
    level=logging.INFO,
    format="%(asctime)s [%(levelname)s] %(name)s: %(message)s",
    datefmt="%H:%M:%S"
)
log = logging.getLogger("MomentumManager")


# ─── Constants ────────────────────────────────────────────────────────────────

FLYWHEEL_I          = 1.24e-4   # kg·m²  — as-built v01 rotor (118g, exact tetra integral of STL)
FLYWHEEL_RPM_MAX    = 20_000    # RPM    — full charge
FLYWHEEL_RPM_MIN    =  5_000    # RPM    — min useful (below = no regen gain)
FLYWHEEL_RPM_IDLE   =  8_000    # RPM    — default hover setpoint
FLYWHEEL_RPM_BOOST  = 18_000    # RPM    — pre-maneuver charge target
REGEN_EFFICIENCY    =  0.72     # 72%    — VESC regen efficiency
DRONE_MASS_KG       =  1.2      # kg
G                   =  9.81     # m/s²
BANK_MAX_DEG        = 30.0      # degrees

# Energy thresholds (Joules)
KE_MAX = 0.5 * FLYWHEEL_I * (FLYWHEEL_RPM_MAX * 2*math.pi/60)**2   # ~272 J
KE_MIN = 0.5 * FLYWHEEL_I * (FLYWHEEL_RPM_MIN * 2*math.pi/60)**2   # ~17 J

# Telemetry ring buffer size
TELEM_BUFFER = 100


# ─── Data Structures ──────────────────────────────────────────────────────────

class FlywheelMode(Enum):
    IDLE      = auto()   # spinning at idle RPM, no active regen
    CHARGING  = auto()   # spinning up to target
    HOLDING   = auto()   # maintaining setpoint
    REGEN     = auto()   # capturing energy from descent/braking
    DISCHARGE = auto()   # releasing energy to assist maneuver
    FAULT     = auto()   # error state


@dataclass
class FlywheelTelemetry:
    rpm:          float = 0.0
    current_a:    float = 0.0
    voltage_v:    float = 0.0
    temp_c:       float = 0.0
    energy_j:     float = 0.0
    charge_pct:   float = 0.0
    mode:         FlywheelMode = FlywheelMode.IDLE
    timestamp:    float = field(default_factory=time.time)

    def update_energy(self):
        omega = self.rpm * 2 * math.pi / 60
        self.energy_j   = 0.5 * FLYWHEEL_I * omega**2
        rpm_clamped     = max(FLYWHEEL_RPM_MIN, min(FLYWHEEL_RPM_MAX, self.rpm))
        self.charge_pct = (rpm_clamped - FLYWHEEL_RPM_MIN) / (FLYWHEEL_RPM_MAX - FLYWHEEL_RPM_MIN) * 100


@dataclass
class FlightTelemetry:
    lat:            float = 0.0
    lon:            float = 0.0
    alt_m:          float = 0.0
    vx_ms:          float = 0.0    # velocity N (m/s)
    vy_ms:          float = 0.0    # velocity E (m/s)
    vz_ms:          float = 0.0    # velocity D (m/s, positive = down)
    roll_deg:       float = 0.0
    pitch_deg:      float = 0.0
    yaw_deg:        float = 0.0
    groundspeed_ms: float = 0.0
    armed:          bool  = False
    mode:           str   = "UNKNOWN"
    battery_pct:    float = 100.0
    battery_v:      float = 0.0
    timestamp:      float = field(default_factory=time.time)

    @property
    def descending(self) -> bool:
        return self.vz_ms > 0.3   # NED: positive vz = descending

    @property
    def ascending(self) -> bool:
        return self.vz_ms < -0.3

    @property
    def kinetic_energy_j(self) -> float:
        speed = math.sqrt(self.vx_ms**2 + self.vy_ms**2 + self.vz_ms**2)
        return 0.5 * DRONE_MASS_KG * speed**2


@dataclass
class EnergyBudget:
    """Current energy accounting across all stores."""
    battery_j:      float = 0.0    # estimated remaining battery energy
    flywheel_j:     float = 0.0    # flywheel kinetic energy
    total_j:        float = 0.0
    regen_total_j:  float = 0.0    # cumulative recovered energy this flight
    assist_total_j: float = 0.0    # cumulative energy discharged to motors

    def update(self, fw: FlywheelTelemetry, fc: FlightTelemetry):
        self.flywheel_j = fw.energy_j
        # Battery estimate: rough from voltage (4S nominal 14.8V, 3000mAh = 159,840 J)
        v_pct = max(0, min(1, (fc.battery_v - 13.2) / (16.8 - 13.2)))
        self.battery_j  = v_pct * 159_840
        self.total_j    = self.battery_j + self.flywheel_j


# ─── VESC Interface ───────────────────────────────────────────────────────────

class VESCInterface:
    """
    Communicates with VESC 4.12 over UART.
    Implements basic VESC packet protocol for RPM control and telemetry.
    Falls back to simulation if hardware not available.
    """

    VESC_COMM_GET_VALUES  = 4
    VESC_COMM_SET_RPM     = 8
    VESC_COMM_SET_CURRENT = 6

    def __init__(self, port: str, baud: int = 115200, sim: bool = False):
        self.sim  = sim
        self._rpm_setpoint = FLYWHEEL_RPM_IDLE
        self._ser = None
        self._lock = threading.Lock()

        # Simulation state
        self._sim_rpm     = 0.0
        self._sim_temp    = 25.0
        self._sim_voltage = 14.8

        if not sim:
            try:
                if serial is None:
                    raise ImportError("pyserial not installed")
                self._ser = serial.Serial(port, baud, timeout=0.1)
                log.info(f"VESC connected on {port} @ {baud}")
            except Exception as e:
                log.warning(f"VESC UART failed ({e}) — switching to simulation")
                self.sim = True

    def set_rpm(self, rpm: float):
        """Command flywheel to target RPM."""
        rpm = max(0, min(FLYWHEEL_RPM_MAX, rpm))
        self._rpm_setpoint = rpm
        if self.sim:
            return
        # VESC COMM_SET_RPM packet (simplified)
        erpm = int(rpm * 7)  # 7 pole pairs for RS2205
        payload = erpm.to_bytes(4, 'big', signed=True)
        self._send_packet(self.VESC_COMM_SET_RPM, payload)

    def set_brake_current(self, amps: float):
        """Apply regenerative braking current."""
        amps = max(-15.0, min(0.0, -abs(amps)))  # always negative for regen
        if self.sim:
            # Simulate energy recovery: reduce RPM proportional to brake
            self._sim_rpm = max(FLYWHEEL_RPM_MIN,
                                self._sim_rpm + amps * 200 * 0.05)
            return
        payload = int(amps * 1000).to_bytes(4, 'big', signed=True)
        self._send_packet(self.VESC_COMM_SET_CURRENT, payload)

    def get_telemetry(self) -> FlywheelTelemetry:
        t = FlywheelTelemetry()
        if self.sim:
            # Simulate flywheel dynamics
            target = self._rpm_setpoint
            diff   = target - self._sim_rpm
            # Spin up/down at ~500 RPM/s
            self._sim_rpm += max(-500, min(500, diff)) * 0.05
            self._sim_rpm  = max(0, self._sim_rpm)
            t.rpm       = self._sim_rpm
            t.voltage_v = self._sim_voltage
            t.current_a = abs(diff) / 5000 * 25   # simulated current
            t.temp_c    = min(65, 25 + t.current_a * 1.5)
        else:
            t = self._read_values()

        t.update_energy()
        return t

    def _send_packet(self, command: int, payload: bytes):
        if self._ser is None:
            return
        with self._lock:
            length  = len(payload) + 1
            packet  = bytes([2, length, command]) + payload
            crc     = self._crc16(bytes([command]) + payload)
            packet += crc.to_bytes(2, 'big') + bytes([3])
            self._ser.write(packet)

    def _read_values(self) -> FlywheelTelemetry:
        # Send GET_VALUES request and parse response
        self._send_packet(self.VESC_COMM_GET_VALUES, b'')
        time.sleep(0.01)
        t = FlywheelTelemetry()
        if self._ser and self._ser.in_waiting > 0:
            data = self._ser.read(self._ser.in_waiting)
            # Parse VESC response (simplified — full impl needs proper framing)
            if len(data) >= 25:
                t.temp_c    = int.from_bytes(data[3:5],   'big') / 10
                t.current_a = int.from_bytes(data[5:9],   'big', signed=True) / 100
                t.voltage_v = int.from_bytes(data[15:17], 'big') / 10
                erpm        = int.from_bytes(data[23:27], 'big', signed=True)
                t.rpm       = abs(erpm) / 7  # 7 pole pairs
        return t

    @staticmethod
    def _crc16(data: bytes) -> int:
        crc = 0
        for b in data:
            crc ^= b << 8
            for _ in range(8):
                crc = (crc << 1) ^ 0x1021 if crc & 0x8000 else crc << 1
        return crc & 0xFFFF


# ─── MAVLink Interface ────────────────────────────────────────────────────────

class FCInterface:
    """
    MAVLink interface to ArduCopter on H743.
    Reads telemetry, monitors flight state for regen triggers.
    """

    def __init__(self, connection: str, baud: int = 115200, sim: bool = False):
        self.sim  = sim
        self._mav = None
        self._telem = FlightTelemetry()
        self._lock  = threading.Lock()

        # Sim state
        self._sim_alt  = 10.0
        self._sim_vz   = 0.0
        self._sim_armed = True

        if not sim:
            try:
                if mavutil is None:
                    raise ImportError("pymavlink not installed")
                self._mav = mavutil.mavlink_connection(connection, baud=baud)
                self._mav.wait_heartbeat(timeout=5)
                log.info(f"FC connected: system {self._mav.target_system}")
                # Request data streams
                self._request_streams()
            except Exception as e:
                log.warning(f"FC MAVLink failed ({e}) — switching to simulation")
                self.sim = True

    def get_telemetry(self) -> FlightTelemetry:
        if self.sim:
            return self._sim_telemetry()
        return self._read_mavlink()

    def send_flywheel_rpm(self, rpm: float):
        """Broadcast flywheel RPM to the FC as NAMED_VALUE_FLOAT 'FWRPM'.

        Consumed by the flywheel_coupling.lua applet on the flight
        controller for gain scheduling and overspeed warnings.
        """
        if self.sim or self._mav is None:
            return
        self._mav.mav.named_value_float_send(
            int(time.time() * 1000) & 0xFFFFFFFF,
            b"FWRPM",
            rpm,
        )

    def _sim_telemetry(self) -> FlightTelemetry:
        """Simulate a simple hover → descend → ascend cycle."""
        t = time.time()
        cycle = t % 30
        if cycle < 10:
            self._sim_vz = 0.0      # hover
        elif cycle < 18:
            self._sim_vz = 1.5      # descend 1.5 m/s
        elif cycle < 26:
            self._sim_vz = -1.5     # ascend
        else:
            self._sim_vz = 0.0      # hover

        self._sim_alt = max(2, self._sim_alt - self._sim_vz * 0.05)

        with self._lock:
            self._telem.alt_m       = self._sim_alt
            self._telem.vz_ms       = self._sim_vz
            self._telem.armed       = self._sim_armed
            self._telem.mode        = "GUIDED"
            self._telem.battery_v   = 15.2
            self._telem.battery_pct = 85.0
            self._telem.timestamp   = time.time()
        return self._telem

    def _read_mavlink(self) -> FlightTelemetry:
        # Drain everything queued since the last tick — telemetry streams
        # arrive faster than the 20Hz loop, one message per tick falls behind.
        updated = False
        while True:
            msg = self._mav.recv_match(
                type=['GLOBAL_POSITION_INT', 'ATTITUDE', 'VFR_HUD',
                      'SYS_STATUS', 'BATTERY_STATUS', 'HEARTBEAT'],
                blocking=False
            )
            if msg is None:
                break

            with self._lock:
                mt = msg.get_type()
                if mt == 'GLOBAL_POSITION_INT':
                    self._telem.lat   = msg.lat / 1e7
                    self._telem.lon   = msg.lon / 1e7
                    self._telem.alt_m = msg.relative_alt / 1000
                    self._telem.vx_ms = msg.vx / 100
                    self._telem.vy_ms = msg.vy / 100
                    self._telem.vz_ms = msg.vz / 100
                    speed = math.sqrt(self._telem.vx_ms**2 + self._telem.vy_ms**2)
                    self._telem.groundspeed_ms = speed
                elif mt == 'ATTITUDE':
                    self._telem.roll_deg  = math.degrees(msg.roll)
                    self._telem.pitch_deg = math.degrees(msg.pitch)
                    self._telem.yaw_deg   = math.degrees(msg.yaw)
                elif mt == 'BATTERY_STATUS':
                    if msg.battery_remaining >= 0:
                        self._telem.battery_pct = msg.battery_remaining
                    if msg.voltages[0] != 65535:
                        self._telem.battery_v = msg.voltages[0] / 1000
                elif mt == 'HEARTBEAT':
                    if msg.type not in (mavutil.mavlink.MAV_TYPE_GCS,
                                        mavutil.mavlink.MAV_TYPE_ONBOARD_CONTROLLER):
                        self._telem.armed = bool(msg.base_mode & 0x80)
                        self._telem.mode  = mavutil.mode_string_v10(msg)
                updated = True

        if updated:
            with self._lock:
                self._telem.timestamp = time.time()
        return self._telem

    def _request_streams(self):
        if self._mav is None:
            return
        for stream_id, rate in [
            (mavutil.mavlink.MAV_DATA_STREAM_POSITION,    5),
            (mavutil.mavlink.MAV_DATA_STREAM_EXTRA1,     10),
            (mavutil.mavlink.MAV_DATA_STREAM_EXTRA2,      5),
            (mavutil.mavlink.MAV_DATA_STREAM_RAW_SENSORS, 2),
        ]:
            self._mav.mav.request_data_stream_send(
                self._mav.target_system,
                self._mav.target_component,
                stream_id, rate, 1
            )


# ─── Momentum Manager ─────────────────────────────────────────────────────────

class MomentumManager:
    """
    Core decision engine.

    Every 50ms:
      1. Poll FC and VESC telemetry
      2. Evaluate energy state
      3. Decide flywheel mode (idle / charge / regen / discharge)
      4. Command VESC accordingly
      5. Log to ring buffer

    Decision logic:
      DESCENDING + flywheel below max → REGEN (capture PE)
      ASCENDING  + flywheel has charge → DISCHARGE (assist climb)
      HOVER      + flywheel below idle → CHARGING
      MANEUVERING (high bank) → pre-charge to BOOST setpoint
      FAULT      → hold last safe RPM, alert
    """

    LOOP_HZ = 20   # 50ms loop

    def __init__(self, vesc: VESCInterface, fc: FCInterface, sim: bool = False):
        self.vesc = vesc
        self.fc   = fc
        self.sim  = sim

        self.fw_telem  = FlywheelTelemetry()
        self.fc_telem  = FlightTelemetry()
        self.budget    = EnergyBudget()

        self._mode     = FlywheelMode.IDLE
        self._running  = False
        self._thread   = None
        self._lock     = threading.Lock()

        # Ring buffers for logging
        self._fw_history  = deque(maxlen=TELEM_BUFFER)
        self._fc_history  = deque(maxlen=TELEM_BUFFER)
        self._event_log   = deque(maxlen=200)

        # Stats
        self._regen_j_total  = 0.0
        self._assist_j_total = 0.0
        self._loop_count     = 0
        self._start_time     = None

    # ── Public API ────────────────────────────────────────────────────────────

    def start(self):
        """Start the background management loop."""
        self._running   = True
        self._start_time = time.time()
        self._thread    = threading.Thread(target=self._loop, daemon=True)
        self._thread.start()
        log.info("MomentumManager started")

    def stop(self):
        """Gracefully stop the loop."""
        self._running = False
        if self._thread:
            self._thread.join(timeout=2)
        self.vesc.set_rpm(0)
        log.info("MomentumManager stopped")

    @property
    def flywheel_mode(self) -> FlywheelMode:
        return self._mode

    @property
    def charge_pct(self) -> float:
        return self.fw_telem.charge_pct

    @property
    def effective_turn_radius(self) -> float:
        """
        Dynamic turn radius for Dubins planner.
        Exported so path planner can query directly.

        High charge → tighter turns allowed (gyroscopic assist available)
        Low charge  → enforce wider turns (protect stability)
        """
        charge = self.fw_telem.charge_pct / 100
        r_min = self._dubins_r_min()
        r_max = r_min * 2.0
        return r_max - (r_max - r_min) * charge

    def request_boost(self):
        """
        Call before a demanding maneuver sequence.
        Spins flywheel up to BOOST setpoint.
        Returns when charged or timeout.
        """
        log.info(f"Boost requested — spinning up to {FLYWHEEL_RPM_BOOST} RPM")
        self.vesc.set_rpm(FLYWHEEL_RPM_BOOST)
        timeout = time.time() + 15
        while time.time() < timeout:
            t = self.vesc.get_telemetry()
            if t.rpm >= FLYWHEEL_RPM_BOOST * 0.95:
                log.info(f"Boost ready: {t.rpm:.0f} RPM")
                return True
            time.sleep(0.2)
        log.warning("Boost timeout — proceeding with available charge")
        return False

    def get_stats(self) -> dict:
        """Return current session energy statistics."""
        elapsed = time.time() - (self._start_time or time.time())
        return {
            "session_s":       round(elapsed, 1),
            "loop_count":      self._loop_count,
            "flywheel_rpm":    round(self.fw_telem.rpm, 0),
            "flywheel_charge": round(self.fw_telem.charge_pct, 1),
            "flywheel_mode":   self._mode.name,
            "flywheel_j":      round(self.fw_telem.energy_j, 1),
            "regen_j_total":   round(self._regen_j_total, 2),
            "assist_j_total":  round(self._assist_j_total, 2),
            "net_recovery_j":  round(self._regen_j_total - self._assist_j_total, 2),
            "effective_r_m":   round(self.effective_turn_radius, 2),
            "turn_radius_m":   round(self._dubins_r_min(), 2),
            "drone_alt_m":     round(self.fc_telem.alt_m, 1),
            "drone_vz_ms":     round(self.fc_telem.vz_ms, 2),
            "battery_pct":     round(self.fc_telem.battery_pct, 1),
        }

    # ── Internal Loop ─────────────────────────────────────────────────────────

    def _loop(self):
        interval = 1.0 / self.LOOP_HZ
        while self._running:
            t0 = time.time()
            try:
                self._tick()
            except Exception as e:
                log.error(f"Loop error: {e}")
                self._set_mode(FlywheelMode.FAULT)
            elapsed = time.time() - t0
            sleep_t = max(0, interval - elapsed)
            time.sleep(sleep_t)

    def _tick(self):
        """Single loop iteration."""
        # 1. Poll telemetry
        fw = self.vesc.get_telemetry()
        fc = self.fc.get_telemetry()

        with self._lock:
            self.fw_telem = fw
            self.fc_telem = fc
            self.budget.update(fw, fc)
            self._fw_history.append(fw)
            self._fc_history.append(fc)

        # 2. Decide mode
        new_mode = self._decide_mode(fw, fc)
        if new_mode != self._mode:
            self._log_event(f"Mode: {self._mode.name} → {new_mode.name} "
                            f"| RPM={fw.rpm:.0f} vz={fc.vz_ms:.2f}")
            self._set_mode(new_mode)

        # 3. Execute mode
        self._execute_mode(fw, fc)

        self._loop_count += 1

        # Broadcast flywheel RPM to FC at 5Hz for the Lua coupling applet
        if self._loop_count % (self.LOOP_HZ // 5) == 0:
            self.fc.send_flywheel_rpm(fw.rpm)

        # 4. Periodic status log (every 5s)
        if self._loop_count % (self.LOOP_HZ * 5) == 0:
            s = self.get_stats()
            log.info(
                f"RPM={s['flywheel_rpm']:.0f} "
                f"({s['flywheel_charge']:.0f}%) "
                f"mode={s['flywheel_mode']:10s} "
                f"regen={s['regen_j_total']:.1f}J "
                f"alt={s['drone_alt_m']:.1f}m "
                f"vz={s['drone_vz_ms']:+.2f}m/s "
                f"r_eff={s['effective_r_m']:.1f}m"
            )

    def _decide_mode(self, fw: FlywheelTelemetry, fc: FlightTelemetry) -> FlywheelMode:
        """State machine decision logic."""

        # Fault conditions
        if fw.temp_c > 80:
            log.warning(f"VESC overheat: {fw.temp_c:.0f}°C")
            return FlywheelMode.FAULT
        if fw.rpm > FLYWHEEL_RPM_MAX * 1.05:
            log.warning(f"Flywheel overspeed: {fw.rpm:.0f} RPM")
            return FlywheelMode.FAULT

        # Not armed / on ground — just idle
        if not fc.armed:
            return FlywheelMode.IDLE

        # Descending meaningfully → capture energy
        if fc.descending and fw.charge_pct < 98:
            return FlywheelMode.REGEN

        # Ascending with charge available → assist
        if fc.ascending and fw.energy_j > KE_MIN * 2:
            return FlywheelMode.DISCHARGE

        # High bank angle (maneuvering) → stay charged
        bank = max(abs(fc.roll_deg), abs(fc.pitch_deg))
        if bank > 20 and fw.charge_pct < 60:
            return FlywheelMode.CHARGING
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

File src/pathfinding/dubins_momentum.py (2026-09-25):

"""
FlyGimbal — Momentum-Aware Dubins Path Planner
src/pathfinding/dubins_momentum.py

Extends standard Dubins path with flywheel state constraints.
Runs on companion computer (Orange Pi Zero 3) via MAVLink to ArduCopter.

Dependencies:
    pip install dubins pymavlink numpy

Usage:
    python dubins_momentum.py --connect /dev/ttyS1 --baud 115200
"""

import math
import os
import sys
import time
import argparse
import numpy as np

# The `dubins` C library is optional: its last release (1.0.1) no longer
# builds on current Python. Without it the planner uses the pure-Python
# sampler from the simulation, which is the one validated in SITL.
try:
    import dubins
    dubins_sample = None
except ImportError:
    dubins = None
    sys.path.insert(0, os.path.join(os.path.dirname(os.path.abspath(__file__)),
                                    "..", "simulation"))
    from gyrodrone_sim import dubins_sample

try:
    from pymavlink import mavutil
except ImportError:
    mavutil = None  # only needed to fly; --sim works without it


# ─── Constants ────────────────────────────────────────────────────────────────

FLYWHEEL_RPM_MAX    = 20_000   # RPM at full charge
FLYWHEEL_RPM_MIN    =  5_000   # Below this, no useful regen
DRONE_MASS_KG       =      1.2
G                   =      9.8
BANK_ANGLE_MAX_DEG  =     30.0 # Max tilt for arc turns
CRUISE_SPEED_MS     =      5.0 # m/s nominal


# ─── Flywheel State (read from VESC via UART) ─────────────────────────────────

class FlywheelState:
    """
    Reads flywheel RPM from VESC over UART.
    Falls back to simulated state if VESC not connected.
    """

    def __init__(self, port: str = "/dev/ttyS3", baud: int = 115200):
        self.rpm      = 0
        self.energy_j = 0.0
        self._sim     = True  # Switch to False when VESC is wired

        # Flywheel rotor moment of inertia (as-built v01, from FLYWHEEL_SPEC.md)
        self.I = 1.24e-4  # kg·m²

        if not self._sim:
            try:
                import serial
                self._ser = serial.Serial(port, baud, timeout=0.1)
            except Exception as e:
                print(f"[FlywheelState] UART open failed: {e} — using simulation")
                self._sim = True

    def update(self):
        """Poll VESC for current RPM."""
        if self._sim:
            # Simulate flywheel draining slowly for testing
            self.rpm = max(FLYWHEEL_RPM_MIN, self.rpm - 50)
            if self.rpm <= FLYWHEEL_RPM_MIN:
                self.rpm = FLYWHEEL_RPM_MAX  # Reset cycle in sim
        else:
            # TODO: implement VESC UART protocol read
            # VESC sends: RPM, current, duty, voltage
            pass

        omega = self.rpm * 2 * math.pi / 60
        self.energy_j = 0.5 * self.I * omega ** 2

    @property
    def charge_fraction(self) -> float:
        """0.0 (empty) to 1.0 (full)"""
        rpm_clamped = max(FLYWHEEL_RPM_MIN, min(FLYWHEEL_RPM_MAX, self.rpm))
        return (rpm_clamped - FLYWHEEL_RPM_MIN) / (FLYWHEEL_RPM_MAX - FLYWHEEL_RPM_MIN)

    def __repr__(self):
        return f"FlywheelState(rpm={self.rpm:.0f}, energy={self.energy_j:.1f}J, charge={self.charge_fraction:.0%})"


# ─── Momentum-Aware Path Planner ─────────────────────────────────────────────

class MomentumDubinsPlanner:
    """
    Plans Dubins paths between waypoints with turning radius
    dynamically adjusted based on flywheel energy state.

    Key insight:
        Tighter turns require more corrective effort from rotors.
        When flywheel has stored energy (high RPM), gyroscopic
        stabilization compensates — tighter turns are "cheaper".
        When flywheel is depleted, enforce gentler arcs.
    """

    def __init__(self, flywheel: FlywheelState):
        self.flywheel = flywheel

    def min_turn_radius(self, speed_ms: float = CRUISE_SPEED_MS) -> float:
        """
        Base minimum turn radius from physics:
            r_min = v² / (g × tan(bank_max))
        """
        bank_rad = math.radians(BANK_ANGLE_MAX_DEG)
        return speed_ms ** 2 / (G * math.tan(bank_rad))

    def effective_turn_radius(self, speed_ms: float = CRUISE_SPEED_MS) -> float:
        """
        Adjusted radius based on flywheel state.

        - Full flywheel (charge=1.0): can use min_turn_radius (tightest)
        - Empty flywheel (charge=0.0): enforce 2× min_turn_radius (gentlest)

        Linear interpolation between these extremes.
        """
        r_min = self.min_turn_radius(speed_ms)
        r_max = r_min * 2.0  # Conservative limit when flywheel empty

        charge = self.flywheel.charge_fraction
        # Invert: high charge → low (tight) radius
        radius = r_max - (r_max - r_min) * charge
        return radius

    def plan_segment(
        self,
        start: tuple,   # (x, y, heading_rad)
        end:   tuple,   # (x, y, heading_rad)
        speed_ms: float = CRUISE_SPEED_MS,
    ) -> list[tuple]:
        """
        Generate Dubins path from start to end configuration.

        Returns list of (x, y, heading_rad) waypoints along the arc.
        """
        self.flywheel.update()
        radius = self.effective_turn_radius(speed_ms)

        if dubins is not None:
            path = dubins.shortest_path(start, end, radius)
            configurations, _ = path.sample_many(step_size=0.5)
            detail = (f"path_type={path.path_type()} "
                      f"| length={path.path_length():.1f}m")
        else:
            configurations = dubins_sample(start, end, radius, step=0.5)
            detail = f"points={len(configurations)} (built-in sampler)"

        print(
            f"[Planner] r={radius:.2f}m | flywheel={self.flywheel} | {detail}"
        )

        return configurations

    def plan_mission(
        self,
        waypoints: list[tuple],  # list of (x, y, heading_deg)
        speed_ms: float = CRUISE_SPEED_MS,
    ) -> list[tuple]:
        """
        Plan full multi-waypoint mission as connected Dubins segments.
        Heading in degrees, converted internally to radians.
        """
        all_configs = []

        for i in range(len(waypoints) - 1):
            wp_start = waypoints[i]
            wp_end   = waypoints[i + 1]

            start = (wp_start[0], wp_start[1], math.radians(wp_start[2]))
            end   = (wp_end[0],   wp_end[1],   math.radians(wp_end[2]))

            segment = self.plan_segment(start, end, speed_ms)
            all_configs.extend(segment)

        return all_configs


# ─── MAVLink Interface ────────────────────────────────────────────────────────
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

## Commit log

2026-05-02 refactor: reorganize into cad-specs/, docs/, src/pathfinding/ structure
2026-05-02 chore: move GitHub-specific files to .github/ conventions
    - ci.yml → .github/workflows/ci.yml
    - bug_report.md → .github/ISSUE_TEMPLATE/bug_report.md
    - feature_request.md → .github/ISSUE_TEMPLATE/feature_request.md
    - pull_request_template.md → .github/PULL_REQUEST_TEMPLATE.md
2026-05-02 feat: add full physics simulation (6-DOF dynamics, flywheel, gimbal, Dubins paths)
    - Disc-frame 6-DOF rigid body with correct NED forces and ZYX Euler angles
    - Flywheel FESS: RPM integration, bearing friction, regenerative braking
    - Gimbal thrust vectoring: two Savox SH-0257MG servos with rate limiting
    - Momentum-aware Dubins path planner (turning radius scales with FW charge)
    - Cascade controller: position->accel->tilt + wrench allocation with gyro FF
    - 4-panel matplotlib dashboard: trajectory, flywheel RPM/energy, regen power,
    gimbal angles, attitude, yaw, ground speed, altitude
    [gyrodrone_sim.py]
2026-05-02 docs: add simulation results, run commands, and validated controller params
    - README: add Quick Start section with full run commands and updated repo tree
    - ROADMAP: add Phase 0.5 (simulation complete) with results table, key findings,
    and validated PID parameters from sim
    - Mark Dubins path tasks as complete (validated in sim)
2026-06-09 feat: momentum manager + SITL integration test (7/7 pass vs real ArduCopter)
    - momentum_manager.py: companion-computer coordinator (VESC flywheel state
    machine, MAVLink FC telemetry, energy budget, dynamic Dubins turn radius)
    - sitl_test.py: flies full mission against ArduCopter SITL in WSL —
    takeoff, 33-point Dubins circuit, descent (REGEN), climb (DISCHARGE), land
    - Fix telemetry lag: drain MAVLink queue per tick (was 1 msg per 50ms loop)
    - Fix flight mode never decoded from heartbeat (stayed UNKNOWN)
    - docs/SITL_TESTING.md: setup, run commands, WSL/SITL gotchas
    - ROADMAP: Week 13 SITL items validated
    [momentum_manager.py, sitl_test.py]
2026-06-09 feat: add v01 CAD geometry (frame, flywheel, gimbal mounts, VESC bracket)
    STL + STEP for all 8 printed/machined parts plus preview SVGs.
    Zips excluded via .gitignore; cad/ geometry un-ignored from the
    global *.stl/*.step rule. Merged duplicate space-named extraction
    dirs into cad/stl/.
    [flywheel_boss_v01.step, flywheel_boss_v01.stl, flywheel_rotor_v01.step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]
2026-06-09 feat: FC Lua flywheel applet + wind/sensor-noise simulation
    Lua applet (src/fc-lua/flywheel_coupling.lua, validated 6/6 in SITL):
    - receives FWRPM from companion (momentum_manager broadcasts at 5Hz)
    - gain-schedules ATC_RAT_RLL/PIT P+D with flywheel RPM (runtime only)
    - overspeed warning + stale-telemetry gain revert failsafe
    - interim mitigation: true rate-loop feed-forward still needs firmware patch
    Simulation realism (gyrodrone_sim.py):
    - Wind model: steady + Gauss-Markov gusts, drag on air-relative velocity
    - SensorNoise: GPS-like position bias, velocity/attitude/gyro white noise;
    controller now flies on measured state when --noise is set
    - new flags: --wind --wind-dir --gust --noise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
    [gyrodrone_sim.py, momentum_manager.py, sitl_lua_test.py]
2026-06-09 fix: reconcile CAD specs with as-built geometry + safety additions
    STL audit (tools/stl_check.py) of v01 parts vs specs found:
    - Rotor inertia: as-built 1.16e-4 kg*m^2 (118g) vs 1.76e-4 assumed
    everywhere -> updated single source of truth in sim (FW_I),
    momentum_manager (FLYWHEEL_I), dubins_momentum, FWC_INERTIA Lua
    default, FLYWHEEL_SPEC, PHYSICS. Sim re-validated: regen 16.7->15.8J,
    tracking/stability unchanged.
    - FLYWHEEL_SPEC errors: 15 Wh goal was 140x off (real: 0.071 Wh stored);
    6000-2RS is deep-groove not angular contact -> 7000C; ERPM cap
    aligned to 20k RPM.
    - NEW: burst containment section (REQUIRED before Phase 2 spin-up) -
    containment_ring_v01 spec + spin-pit test p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
    [dubins_momentum.py, gyrodrone_sim.py, momentum_manager.py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]
2026-06-09 fix: baro-class altitude noise model (was overstating alt error 4x)
    Isolation runs showed sensor noise, not wind, drove the altitude
    degradation - and specifically the GPS-class Gauss-Markov bias on z.
    Real FCs fuse barometer for altitude (sigma ~0.1m), never raw GPS z,
    and no controller can correct an estimation bias. z now uses baro-class
    noise (0.1m bias tau=30s); x/y keep GPS-class bias.
    Results: noise-only alt error 0.93 -> 0.26m mean; 5m/s wind + noise
    1.07 -> 0.29m. Existing alt PID is fine; ROADMAP finding added.
    (Tried LPF on measurements first - made it worse by lagging the vz
    damping path; reverted.)
    [gyrodrone_sim.py]
2026-06-09 feat: firmware flywheel feed-forward validated in patched SITL (7/7)
    Built ArduPilot master @ 1b7d3cde with the AC_AttitudeControl patch
    (set_flywheel_momentum binding + 400Hz H-cross-gyro term in the rate
    loop). Lua applet auto-detected the binding and announced firmware
    feed-forward active. Stale failsafe zeroes the FF and reverts gains.
    - src/firmware-patch/flywheel_ff.patch: exported git diff (exact
    validated change, applies to 1b7d3cde)
    - src/firmware-patch/README.md: design, build, validation, tuning notes
    - docs/SITL_TESTING.md: patched-firmware test section
    - docs/ROADMAP.md: Phase 4 feed-forward item checked off
2026-06-09 feat: v02 CAD generation + corrected rotor inertia (1.16e-4 -> 1.24e-4)
    New parametric generator (tools/generate_cad_v02.py, CadQuery) producing
    STL + STEP (+ DXF for plates):
    - frame_bottom_v02: ring band 45->14mm, 164g (was 255g as-built)
    - frame_top_v02: R80 electronics tray, 56g (was 201g) — plates -52%
    - containment_cup_v01: one-piece burst containment (ID86, 3mm wall,
    integral floor, ears on R62) — unblocks Phase 2 spin-up
    - flywheel_rotor_v02: optional heavy rotor, I=1.78e-4, 164g, 389J
    Inertia correction: stl_check.py used a centroid point-mass
    approximation that ran ~7% low; replaced with the exact tetrahedron
    integral (validated against analytic v02 rotor: 1.770e-4 vs 1.776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
    [containment_cup_v01.step, containment_cup_v01.stl, flywheel_rotor_v02.step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]
2026-06-09 docs: cad README fabrication guide - what to order where vs 3D print
2026-06-09 feat: assembled/exploded prototype render + shelve superseded v01 geometry
    tools/render_assembly.py renders cad/preview_assembly.png from the
    released STLs (painter's algorithm, no new deps). Includes the user's
    move of superseded frame/rotor v01 files into stl/v01/ and stl/step/v01/;
    README paths updated — note flywheel_rotor_v01 remains the DEFAULT rotor
    to machine despite living under v01/.
    [flywheel_rotor_v01.step, flywheel_rotor_v01.stl, frame_bottom_v01.step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]
2026-06-09 chore: restore default rotor v01 (STL+STEP) to main cad folders
    The active part lives in the main folder; only the superseded v01
    frame plates stay shelved under v01/. README paths updated.
    [flywheel_rotor_v01.step, flywheel_rotor_v01.stl]
2026-06-09 feat: show thrust-vector gimbals in prototype render
    The front motor pair now renders tilted 12 deg on its pivot with motor
    plate + Savox servo block (red), per GIMBAL_SPEC — the project's
    namesake feature was invisible with identical placeholder motors.
2026-06-09 docs: sync README + ROADMAP with actual progress
    README: repo structure (cad/, tools/, momentum-manager, fc-lua,
    firmware-patch), SITL/firmware validation milestones, prototype render.
    ROADMAP: Phase 1 CAD items checked off (v02 plates, DXF, rotor STEP),
    remaining ordering/Fusion items listed; Phase 2 gains containment cup +
    spin-pit gate.
2026-06-10 feat: add SITL flight demo script for arming, takeoff, hovering, and landing
2026-09-25 feat: add initial documentation for FlyGimbal framework structure
2026-09-25 feat: update project name from GyroDrone to FlyGimbal across all files
    - Updated CI workflow to reflect new project name and added simulation step.
    - Enhanced README with detailed project description and updated links.
    - Modified specifications and documentation files to replace "GyroDrone" with "FlyGimbal".
    - Added smoke tests for simulation and path planner functionality.
    - Updated requirements and CAD generation scripts to align with new naming.
    - Introduced LICENSE file for project licensing.
    [dubins_momentum.py, generate_cad_v02.py, gyrodrone_sim.py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]
